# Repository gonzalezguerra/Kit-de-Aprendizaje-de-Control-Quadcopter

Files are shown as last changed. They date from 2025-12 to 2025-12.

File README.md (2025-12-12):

# Proyecto Educativo de Control con ESP32 y UAV (DXF + Firmware + Materiales)

Este repositorio reúne todos los recursos necesarios para que cualquier estudiante pueda **aprender control automático de manera económica y práctica**, utilizando una **ESP32**, sensores estándar y una estructura de dron diseñada para corte láser.

El proyecto incluye:
- Diseño del frame en **DXF**
- Firmware completo para **PlatformIO**
- Lista detallada de componentes y costos
- Guías prácticas para montaje y pruebas
- Material para extender el proyecto en cursos de control

---

# 🧩 Descripción General

Este proyecto está diseñado como una plataforma accesible para experimentar con:

- Control PID  
- Limitaciones físicas del control (saturación, ruido, retardo)
- Integración de sensores (IMU, magnetómetro, ToF)
- Actuadores (motores brushless + ESC)
- Modelación y simulación
- Construcción de UAV educativo

---

# 🛠️ Componentes y Costos Estimados

La siguiente tabla representa los costos aproximados para replicar la plataforma (valores en CLP).

> Esta tabla proviene del diseño original en LaTeX del proyecto, convertida a formato Markdown para uso en GitHub.

### **Tabla de costos (Markdown)**

| **Componente** | **Costo Estimado (CLP)** | **Proveedor** |
|---|---|---|
| **Cuerpo UAV** | | |
| Base madera 3 mm | $2.500 | Sodimac |
| Corte láser | $7.000 | Tago |
| Soportes PLA (impresión 3D) | ≈ $2.000 | Bibliotecas UC |
| **Alimentación y Actuadores** | | |
| Batería LiPo 11.1 V, 3000 mAh | $17.600 | Aliexpress |
| Motores brushless 2212 2200 KV (x4) | $36.000 | AFEL |
| Drivers ESC 30 A (x4) | $17.200 | Aliexpress |
| Conectores XT60 PCB | $7.500 | Aliexpress |
| Adaptadores XT60 a T | $8.000 | AFEL |
| Hélices fibra de carbono | $11.000 | AFEL |
| **Electrónica** | | |
| ESP32 (38 pines) | $5.000 | Aliexpress |
| MPU6050 (IMU) | $4.000 | AFEL |
| Magnetómetro HMC5883L | $3.500 | AFEL |
| Sensor distancia láser VL53L0X | $6.000 | AFEL |
| **TOTAL ESTIMADO** | **$127.300** | |

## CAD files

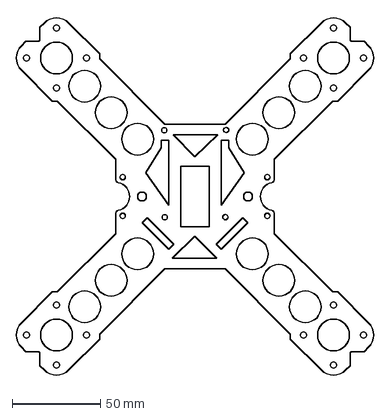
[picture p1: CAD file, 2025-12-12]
CorteDron.dxf
202.4 x 204.4 mm

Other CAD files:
Patas Quadcopter.f3d

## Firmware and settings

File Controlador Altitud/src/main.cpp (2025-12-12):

#include <Arduino.h>
#include <Wire.h>
#include <WiFi.h>
#include <LittleFS.h>
#include <FS.h>
#include <AsyncTCP.h>
#include <ESPAsyncWebServer.h>
#include <WiFiUdp.h>
#include <math.h> 

// Módulos
#include "sensores.h"
#include "MadgwickAHRS.h"
#include "LQRController.h"
#include "AltitudePID.h"
#include "Ultrasonic.h"

// ==========================================================
//                         CONSTANTES GLOBALES
// ==========================================================

// --- Frecuencias de Lazo ---
const int ATTITUDE_LOOP_HZ = 150;
const TickType_t xFrequencyAttitude = pdMS_TO_TICKS(1000 / ATTITUDE_LOOP_HZ);

const int ALTITUDE_LOOP_HZ = 40;
const TickType_t xFrequencyAltitude = pdMS_TO_TICKS(1000 / ALTITUDE_LOOP_HZ);

const int TELEMETRY_LOOP_HZ = 10; // Frecuencia de la telemetria. 5-20 Hz
const uint32_t TELEMETRY_INTERVAL_MS = 1000 / TELEMETRY_LOOP_HZ;

// Heartbeat variables (ahora solo como marcador, no como failsafe activo)
volatile uint32_t g_last_heartbeat_ms = 0;
const uint32_t HEARTBEAT_TIMEOUT_MS = 200; // Mantenido, pero no usado para failsafe

// --- Controladores y Filtros ---
MadgwickAHRS* ahrs;
LQRController* attitudeController;
AltitudePID* altController;

// --- Pines y Hardware ---
const int SDA_PIN = 21;
const int SCL_PIN = 22;
const int TRIG_PIN = 25;
const int ECHO_PIN = 26;

static const uint8_t PWM_PINS[4] = {32, 27, 4, 2}; // M1, M2, M3, M4
static const uint8_t LEDC_CH[4] = {0, 1, 2, 3}; // Canales LEDC para PWM
static const uint8_t LEDC_RES_BITS = 16;
static const uint32_t SERVO_FREQ_HZ = 50;      // Frecuencia PWM para ESCs
static const uint16_t PULSE_MIN_US = 1100;
static const uint16_t PULSE_MAX_US = 2100;

// Objetos de Sensores (Globales)
Adafruit_MPU6050 mpu;
Adafruit_HMC5883_Unified mag = Adafruit_HMC5883_Unified(12345);
Ultrasonic ultrasonic(TRIG_PIN, ECHO_PIN);
Adafruit_VL53L0X lox = Adafruit_VL53L0X();

// --- Calibración ---
float g_b[3] = {-0.01f, -0.06f, -0.02f};
float a_A[3][3] = {
    {1.002644, -0.004764, -0.004747 },
    { 0.050504, 0.985736, 0.003380 },
    { -0.004747, -0.002533, 0.979294 }
};
float a_b[3] = {0.268676, 0.140280, 0.152916};
float m_A[3][3] = {
    {1.114758, 0.013255, 0.007983},
    {0.013255, 1.048723, -0.005001},
    {0.007983, -0.005001, 1.027957}
};
float m_b[3] = {8.096708, -6.303482, -7.222026};

// GANANCIAS LQR
Matrix3x3 K_i_gains = {{{0.1f, 0.0f, 0.0f}, 
                        {0.0f, 0.1f, 0.0f}, 
                        {0.0f, 0.0f, 0.00f}}};
Matrix3x3 K_q_gains = {{{3.5f, 0.0f, 0.0f}, 
                        {0.0f, 3.5f, 0.0f}, 
                        {0.0f, 0.0f, 0.0f}}};
Matrix3x3 K_w_gains = {{{0.3f, 0.0f, 0.0f}, 
                        {0.0f, 0.3f, 0.0f}, 
                        {0.0f, 0.0f, 0.0f}}};

// ==========================================================
//               ESTADO COMPARTIDO (CON MUTEX)
// ==========================================================

SemaphoreHandle_t xStateMutex;

struct SharedControlState {
    float roll_deg, pitch_deg, yaw_deg; 
    Vector3f torques = {0.0f, 0.0f, 0.0f}; 
    float altitude_cm = 0.0f;
    float throttle_base = 0.0f;
} sharedState;

// Flags de Estado y Comandos (accedidas por red y tareas)
#define FLAG_ARMED (1 << 0) 
volatile int16_t g_setpoint_cm = 40; 
volatile uint8_t g_flags = 0; 
const float THROTTLE_HOVER = 0.45f;

// ==========================================================
//               FUNCIONES AUXILIARES (PWM, MATH)
// ==========================================================

static inline float clampf(float v, float lo, float hi) {
    if (v < lo) return lo;
    if (v > hi) return hi;
    return v;
}

static inline int8_t clamp_i8_deg(float d){
    if (d > 127) return 127;
    if (d < -128) return -128;
    return (int8_t)lrintf(d);
}

inline uint32_t periodUs() { return 1000000UL / SERVO_FREQ_HZ; }
inline uint32_t maxDuty() { return (1UL << LEDC_RES_BITS) - 1; }

uint32_t pulseToDuty(uint32_t pulse_us) {
    return (uint64_t)pulse_us * maxDuty() / periodUs();
}

void writePulseUs(uint8_t motor_index, uint16_t us) {
    if (us < PULSE_MIN_US) us = PULSE_MIN_US;
    if (us > PULSE_MAX_US) us = PULSE_MAX_US;
    ledcWrite(LEDC_CH[motor_index], pulseToDuty(us));
}

uint16_t floatToPulseUs(float value) {
        return PULSE_MIN_US + (uint16_t)(value * (PULSE_MAX_US - PULSE_MIN_US));
}

// ==========================================================
//    TAREA 1: CONTROL DE ACTITUD (CORE 1 - ALTA PRIORIDAD)
// ==========================================================
void Task_AttitudeControl(void *pvParameters) {
    Serial.println("Tarea de Actitud iniciada en Core 1.");
    TickType_t xLastWakeTime = xTaskGetTickCount();
    const float dt = 1.0f / ATTITUDE_LOOP_HZ;

    if ((g_flags & FLAG_ARMED) && (millis() - g_last_heartbeat_ms > HEARTBEAT_TIMEOUT_MS)) {
        Serial.println("[FAILSAFE] Heartbeat perdido. DESARMANDO MOTORES.");
        g_flags &= ~FLAG_ARMED;
    }       
    
    for (;;) {
        // ALTITUD
        Vector3f torques_local = {0.0f, 0.0f, 0.0f};

        float throttle_base_local;

        if (xSemaphoreTake(xStateMutex, (TickType_t)0) == pdTRUE) {
                throttle_base_local = sharedState.throttle_base;
                xSemaphoreGive(xStateMutex);
        }

        float roll_cmd = torques_local.x;
        float pitch_cmd = torques_local.y;
        float yaw_cmd = torques_local.z;


        float motor1_out = throttle_base_local -roll_cmd + pitch_cmd;
        float motor2_out = throttle_base_local -roll_cmd - pitch_cmd;
        float motor3_out = throttle_base_local + roll_cmd + pitch_cmd;
        float motor4_out = throttle_base_local + roll_cmd - pitch_cmd;

        if (g_flags & FLAG_ARMED) {
            writePulseUs(0, floatToPulseUs(clampf(motor1_out, 0.0f, 0.65f)));
            writePulseUs(1, floatToPulseUs(clampf(motor2_out, 0.0f, 0.65f)));
            writePulseUs(2, floatToPulseUs(clampf(motor3_out, 0.0f, 0.65f)));
            writePulseUs(3, floatToPulseUs(clampf(motor4_out, 0.0f, 0.65f)));
        } else {
    // Desarmado: Pulso Mínimo (1000us)
        for (int i = 0; i < 4; i++) writePulseUs(i, PULSE_MIN_US);
        }
    vTaskDelayUntil(&xLastWakeTime, xFrequencyAttitude);
    }
}

// ==========================================================
//    TAREA 2: CONTROL DE ALTITUD (CORE 1 - BAJA PRIORIDAD)
// ==========================================================
void Task_AltitudeControl(void *pvParameters) {
    Serial.println("Tarea de Altitud iniciada en Core 1.");
    TickType_t xLastWakeTime = xTaskGetTickCount();
    const float dt = 1.0f / ALTITUDE_LOOP_HZ;
    auto median3 = [](float a, float b, float c){ 
        if (a > b) { float t=a; a=b; b=t; } if (b > c) { float t=b; b=c; c=t; } if (a > b) { float t=a; a=b; b=t; } return b; 
    };

    for (;;) {
        VL53L0X_RangingMeasurementData_t m;
        lox.rangingTest(&m, false); float t1 = m.RangeMilliMeter;
        lox.rangingTest(&m, false); float t2 = m.RangeMilliMeter;
        lox.rangingTest(&m, false); float t3 = m.RangeMilliMeter;
        float tof_cm = 0.1f * median3(t1, t2, t3);
        // Fusión y Limitación
        float altitud_local = clampf(tof_cm, 0.0f, 150.0f); // 1.5 metros max

        // 2. Ejecutar Controlador PID
        float altitud_deseada = (float)g_setpoint_cm;
        float pid_correction = 0.0f;
        float throttle_base_local = THROTTLE_HOVER;

        if (g_flags & FLAG_ARMED) {
            pid_correction = altController->update(altitud_deseada, altitud_local, dt);
            throttle_base_local = THROTTLE_HOVER + pid_correction;
            throttle_base_local = clampf(throttle_base_local, 0.0f, 0.65f);
            Serial.printf("Setpoint: %d cm, medida: %.1f cm, throttle_base: %.2f, (P: %.3f, I: %.3f, D: %.3f)\n",
                        g_setpoint_cm, altitud_local, throttle_base_local,
                        altController->lastP(),
                        altController->lastI(),
                        altController->lastD());
        }
        // 3. Actualizar el Estado Compartido (¡CON MUTEX!)
        if (xSemaphoreTake(xStateMutex, (TickType_t)5) == pdTRUE) {
            sharedState.altitude_cm = altitud_local;
            sharedState.throttle_base = throttle_base_local;
            xSemaphoreGive(xStateMutex);
        }
        vTaskDelayUntil(&xLastWakeTime, xFrequencyAltitude);
    }
}

// ==========================================================
//                   LÓGICA DE TELEMETRÍA (IOT)
//                     (CORE 0 - ASÍNCRONO)
// ==========================================================

// --- Variables de Red ---
AsyncWebServer server(80);
AsyncWebSocket ws("/ws");
WiFiUDP udpRx;
WiFiUDP udpTx;
static const uint16_t UDP_PORT_TX = 4000;
static const uint16_t UDP_PORT_RX = 4001;
static const IPAddress BROADCAST_IP(192,168,4,255);
static uint8_t g_seq = 0;
static IPAddress lastClientIP = IPAddress(0,0,0,0);

struct __attribute__((packed)) Telemetry {
        int16_t yaw_cdeg; 
        int8_t   pitch_d;
        int8_t   roll_d; 
        uint16_t alt_cm;
        uint8_t  flags; 
        uint8_t  seq;
};

static constexpr size_t TELEMETRY_SIZE = sizeof(Telemetry);
static uint8_t telemetryBuf[TELEMETRY_SIZE];
static Telemetry* telPtr = reinterpret_cast<Telemetry*>(telemetryBuf);

// --- Funciones de IOT ---

static void handleUdpRx() {
    int pkt = udpRx.parsePacket();
    if (pkt <= 0) return;
    uint8_t buf[64]; int r = udpRx.read(buf, sizeof(buf));
    if (r <= 0) return;
    g_last_heartbeat_ms = millis(); 
    if (r == 2) {
    int16_t sp = (int16_t)((uint16_t)buf[0] | ((uint16_t)buf[1]<<8));
    g_setpoint_cm = constrain(sp, 0, 300);
    }
}

static void fillTelemetryFromSensors() {
    float r=0.0f, p=0.0f, y=0.0f, alt=0.0f;
    // Leer el estado compartido de forma segura
    if (xSemaphoreTake(xStateMutex, (TickType_t)5) == pdTRUE) {
        r = sharedState.roll_deg;
        p = sharedState.pitch_deg;
        y = sharedState.yaw_deg;
        alt = sharedState.altitude_cm;
        xSemaphoreGive(xStateMutex);
    }   
    // Llenar el paquete de telemetría con datos escalados
    telPtr->yaw_cdeg = (int16_t)lrintf(clampf(y, -180.0f, 180.0f) * 100.0f);
    telPtr->pitch_d  = clamp_i8_deg(p);
    telPtr->roll_d   = clamp_i8_deg(r);
    telPtr->alt_cm   = (uint16_t)lrintf(clampf(alt, 0.0f, 65535.0f));
    telPtr->flags    = g_flags;
    telPtr->seq      = g_seq++;
}

static void sendTelemetry(const uint8_t *buf, size_t len) {
    if (ws.count() > 0) {
        ws.binaryAll((const char*)buf, len); 
        return; 
    }

    if (lastClientIP[0] != 0) { 
        udpTx.beginPacket(lastClientIP, UDP_PORT_TX); udpTx.write(buf, len); udpTx.endPacket(); return;
    }
    if (WiFi.softAPgetStationNum() > 0) {
        udpTx.beginPacket(BROADCAST_IP, UDP_PORT_TX); udpTx.write(buf, len); udpTx.endPacket();
    }
}

static void onWsEvent(AsyncWebSocket *serverPtr, AsyncWebSocketClient *client, AwsEventType type, void *arg, uint8_t *data, size_t len) {
    switch(type){
        case WS_EVT_CONNECT:
            lastClientIP = client->remoteIP();
            Serial.printf("[WS] Cliente conectado: %s\n", lastClientIP.toString().c_str());
            client->client()->setNoDelay(true);
            break;

        case WS_EVT_DISCONNECT:
            if (g_flags & FLAG_ARMED) { 
                Serial.println("[FAILSAFE] Cliente desconectado. DESARMANDO.");
                g_flags &= ~FLAG_ARMED; 
            } else {
                Serial.println("[WS] Cliente desconectado.");
            }
            if (lastClientIP == client->remoteIP()) lastClientIP = IPAddress(0,0,0,0);
            break;

        case WS_EVT_DATA: { // <--- AQUI AGREGUE LA LLAVE DE APERTURA
            AwsFrameInfo *info = (AwsFrameInfo*)arg;
            
            // Solo procesamos si es un mensaje de texto completo y es el frame final
            if (info->final && info->index == 0 && info->len == len && info->opcode == WS_TEXT) {
                
                // Asegurar terminación nula
                data[len] = 0;
                String mensaje = (char*)data;
                
                int nuevo_setpoint = -1;
                
                // Lógica de parseo
                if (mensaje.startsWith("ALT:")) {
                    nuevo_setpoint = mensaje.substring(4).toInt();
                } else if (isdigit(mensaje.charAt(0))) {
                    nuevo_setpoint = mensaje.toInt();
                }

                if (nuevo_setpoint >= 0) {
                    g_setpoint_cm = constrain(nuevo_setpoint, 0, 300);
                    g_last_heartbeat_ms = millis(); 
                    Serial.printf("[WS] Setpoint recibido: %d cm\n", g_setpoint_cm);
                } else {
                    Serial.printf("[WS] Comando no reconocido: %s\n", mensaje.c_str());
                }
            }
            break; 
        }

        default: break;
    }
}

static void setupAP(){
    WiFi.mode(WIFI_AP);
    WiFi.softAP("DRON_ESP32","12345678");
    WiFi.softAPConfig(IPAddress(192,168,4,1), IPAddress(192,168,4,1), IPAddress(255,255,255,0));
}

static void setupFS(){ if (!LittleFS.begin()) { LittleFS.format(); LittleFS.begin(); } }

static void setupServer(){
    ws.onEvent(onWsEvent);
    server.addHandler(&ws);

    server.on("/arm", HTTP_GET, [](AsyncWebServerRequest *request){
        g_last_heartbeat_ms = millis();
        g_flags |= FLAG_ARMED;
        Serial.println("[HTTP] ARMADO. Motores listos.");
        request->send(200, "text/plain", "ARMED");
    });

    server.on("/disarm", HTTP_GET, [](AsyncWebServerRequest *request){
        g_flags &= ~FLAG_ARMED;
        Serial.println("[HTTP] DESARMADO. Motores detenidos.");
        request->send(200, "text/plain", "DISARMED");
    });

    server.on("/set_alt", HTTP_GET, [](AsyncWebServerRequest *request){
        if (request->hasParam("cm")) {
            int cm = request->getParam("cm")->value().toInt();
            g_setpoint_cm = (int16_t)constrain(cm, 0, 300);
            g_last_heartbeat_ms = millis();
            Serial.printf("[HTTP] Setpoint actualizado: %d cm\n", g_setpoint_cm);
            request->send(200, "text/plain", "OK");
        } else {
            // Agrega este log para depurar si el cliente manda mal el parametro
            Serial.println("[HTTP ERROR] Petición a /set_alt sin parámetro 'cm'");
            
            // Listar qué parametros llegaron para ver cómo lo está enviando el dashboard
            int params = request->params();
            for(int i=0;i<params;i++){
                AsyncWebParameter* p = request->getParam(i);
                Serial.printf("Param recibido: %s = %s\n", p->name().c_str(), p->value().c_str());
            }
            request->send(400, "text/plain", "Missing cm parameter");
        }
    });

    server.serveStatic("/", LittleFS, "/").setDefaultFile("index.html").setCacheControl("no-cache");
    server.begin();
}

// ==========================================================
//                   CONFIGURACIÓN PRINCIPAL
// ==========================================================
void setup() {
    Serial.begin(115200);
    delay(100);
   Serial.println("Iniciando sistema DUAL-CORE...");

    // 1. Inicializar Sensores y Controladores
   Wire.begin(SDA_PIN, SCL_PIN, 400000); 
   if(!mpu.begin()) { 
        Serial.println("MPU6050 no responde."); 
        while(1) 
        delay(10); 
    }
    mpu.setAccelerometerRange(MPU6050_RANGE_2_G);
    mpu.setGyroRange(MPU6050_RANGE_500_DEG);
    mpu.setFilterBandwidth(MPU6050_BAND_21_HZ);
    if(!mag.begin()) { 
        Serial.println("HMC5883L no responde."); 
        while(1) 
        delay(10); 
    }
    if(!lox.begin()) { 
        Serial.println("VL53L0X (ToF) no responde."); 
        while (1) 
        delay(10); 
    }
    lox.startRangeContinuous(); 
    Serial.println("Sensores inicializados.");

    // Inicializar Controladores
    // il PID
    ahrs = new MadgwickAHRS(0.1f);
    attitudeController = new LQRController();
    attitudeController->setGains(K_i_gains, K_q_gains, K_w_gains);
    altController = new AltitudePID();

    // Dale tu taglio Goatcaz
    float alt_kp = 0.0065f; 
    float alt_ki = 0.017f;
    float alt_kd = 0.002f;

    altController->setGains(alt_kp, alt_ki, alt_kd);         // PID
    altController->setLimits(-0.0f, 0.2f);
    altController->setAntiWindup(-5.0f, 5.0f);

    // 2. Setup de PWM (Motores)
    Serial.println("Configurando PWM y Armado de ESCs...");
    for (int i = 0; i < 4; i++) {
        ledcSetup(LEDC_CH[i], SERVO_FREQ_HZ, LEDC_RES_BITS);
        ledcAttachPin(PWM_PINS[i], LEDC_CH[i]);
        writePulseUs(i, PULSE_MIN_US);
    }
    delay(3000); 
    Serial.println("ESCs armados. Motores en IDLE (1000us).");

    // 3. Crear Mutex y Comunicación IoT (CORE 0)

    xStateMutex = xSemaphoreCreateMutex();
    if (xStateMutex == NULL) { 
        Serial.println("Error al crear Mutex!");
        while(1); 
    } else {
    setupAP();
    WiFi.setSleep(false);
    setupFS();
    setupServer();
    udpTx.begin(WiFi.softAPIP(), 0);
    size_t udp_status = udpRx.begin(UDP_PORT_RX); 
    if (udp_status != 1) { 
        Serial.println("[ERROR FATAL] Fallo al iniciar UDP RX en puerto 4001.");
        while(1); 
    }
    }
    
    // 4. Crear Tareas de FreeRTOS (Core 1 para Control)
    xTaskCreatePinnedToCore(Task_AttitudeControl, "Attitude", 10000, NULL, 2, NULL, 1); 
    xTaskCreatePinnedToCore(Task_AltitudeControl, "Altitude", 4096, NULL, 2, NULL, 1);

    Serial.println("Control de vuelo en Core 1. Comunicaciones en Core 0.");
    Serial.println(">>> Accede a http://192.168.4.1 y usa /arm para activar el vuelo. <<<");
}


// ==========================================================
//             TAREA 3: BUCLE PRINCIPAL (CORE 0)
// ==========================================================
// --- TAREA 3: BUCLE PRINCIPAL (CORE 0) ---
void loop() {
    static uint32_t lastTelemetryTx = 0;
    uint32_t now = millis();
    static uint32_t lastCleanup = 0;
    const uint32_t CLEANUP_INTERVAL_MS = 1000;

    // 1. Recibir Comandos UDP
    handleUdpRx();

    // 2. Mantenimiento de Conexiones (Aislado al inicio del loop)
    // HACEMOS LA LIMPIEZA AHORA, ANTES DE ENVIAR LA TELEMETRÍA.
    if (now - lastCleanup >= CLEANUP_INTERVAL_MS) {
        lastCleanup = now;
        ws.cleanupClients(); 
    }
    
    // 3. Enviar Telemetría (10 Hz)
    bool is_client_present = (ws.count() > 0 || WiFi.softAPgetStationNum() > 0);
    if (is_client_present && (now - lastTelemetryTx >= TELEMETRY_INTERVAL_MS)) {
        lastTelemetryTx = now;
        fillTelemetryFromSensors();
        sendTelemetry(telemetryBuf, TELEMETRY_SIZE);
    }
    
    // Cede el tiempo de CPU, dando más espacio al scheduler
    vTaskDelay(pdMS_TO_TICKS(5)); 
}

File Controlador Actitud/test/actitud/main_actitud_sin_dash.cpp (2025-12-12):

#include <Arduino.h>
#include <Wire.h>
#include "sensores.h"
#include "MadgwickAHRS.h"   // Filtro Madgwick
#include "LQRController.h"  // Controlador LQR
#include "AltitudePID.h"    // Controlador de Altura PID
#include "Ultrasonic.h"     // Sensor Ultrasónico

// clampf: Función auxiliar para limitar valores flotantes
static inline float clampf(float v, float lo, float hi) {
    if (v < lo) return lo;
    if (v > hi) return hi;
    return v;
}

// --- Frecuencias de Lazo ---
// Frecuencia del lazo de actitud (150 Hz = 6.67ms). Rango entre 150 y 250 Hz
const int ATTITUDE_LOOP_HZ = 150;
const TickType_t xFrequencyAttitude = pdMS_TO_TICKS(1000 / ATTITUDE_LOOP_HZ);

// Frecuencia del lazo de altitud (40 Hz = 25ms)
const int ALTITUDE_LOOP_HZ = 40;
const TickType_t xFrequencyAltitude = pdMS_TO_TICKS(1000 / ALTITUDE_LOOP_HZ);

// --- Controladores y Filtros ---
MadgwickAHRS* ahrs;
LQRController* attitudeController;
AltitudePID* altController;

// --- Pines para sensores ---
const int SDA_PIN = 21;
const int SCL_PIN = 22;
const int TRIG_PIN = 25;
const int ECHO_PIN = 26;

// ----------------------------- PWM ------------------------------

// Pines de motores (PWM)
static const uint8_t PWM_PINS[4] = {32, 27, 4, 2}; // M1, M2, M3, M4
static const uint8_t LEDC_CH[4] = {0, 1, 2, 3}; // Canales LEDC para PWM

// Parametros de PWM
static const uint8_t LEDC_RES_BITS = 16; // Resolución de 16 bits
static const uint32_t SERVO_FREQ_HZ = 50; // Frecuencia típica de ESCs (50 Hz)
static const uint16_t PULSE_MIN_US = 1100; // Minimo para que giren
static const uint16_t PULSE_MAX_US = 2100; // Maximo para que giren
static const uint16_t PULSE_IDLE_US = 1050; // IDLE

// AUX PWM
inline  uint32_t periodUs() {
    return 1000000UL / SERVO_FREQ_HZ;       // 20000us para 50Hz
}
inline uint32_t maxDuty() {
    return (1UL << LEDC_RES_BITS) - 1;      // 65535 para 16 bits
}

/**
 * @brief Convierte microsegundos de pulso a valor de duty cycle para PWM.
 */
uint32_t pulseToDuty(uint32_t pulse_us) {
    return (uint64_t)pulse_us * maxDuty() / periodUs();
}

/**
 * @brief Escribe un ancho de pulso en microsegundos a un canal de motor
 */
void writePulseUs(uint8_t motor_index, uint16_t us) {
    if (us < PULSE_MIN_US) us = PULSE_MIN_US;
    if (us > PULSE_MAX_US) us = PULSE_MAX_US;
    ledcWrite(LEDC_CH[motor_index], pulseToDuty(us));
}

/**
 * @brief Convierte la salida del mezclador a un pulso
 */
uint16_t floatToPulseUs(float value) {
    return PULSE_MIN_US + (uint16_t)(value * (PULSE_MAX_US - PULSE_MIN_US));
}

// ----------------------------- fin PWM ------------------------------

// Objetos de Sensores (Globales)
Adafruit_MPU6050 mpu;
Adafruit_HMC5883_Unified mag = Adafruit_HMC5883_Unified(12345);
Ultrasonic ultrasonic(TRIG_PIN, ECHO_PIN);
Adafruit_VL53L0X lox = Adafruit_VL53L0X();

// Kill switch (Interruptor de emergencia)
volatile bool g_ESTOP_ACTIVADO = false;

// Matrices de Calibración (Globales)
//float g_b[3] = { -0.01f + 0.00056284f, -0.06f + 0.00180133f, -0.02f + 0.00563336f };
float g_b[3] = {-0.01f, -0.06f, -0.02f};
float a_A[3][3] = {
    {1.002644, -0.004764, -0.004747 },
    { 0.050504, 0.985736, 0.003380 },
    { -0.004747, -0.002533, 0.979294 }
};

float a_b[3] = {0.268676, 0.140280, 0.152916};
float m_A[3][3] = {
    {1.114758, 0.013255, 0.007983},
    {0.013255, 1.048723, -0.005001},
    {0.007983, -0.005001, 1.027957}
};
float m_b[3] = {8.096708, -6.303482, -7.222026};

float a_calibrado[3];
float g_calibrado[3];
float m_calibrado[3];
float roll, pitch, yaw;

// GANANCIAS LQR (Globales)

Matrix3x3 K_i_gains = {{{0.06f, 0.0f, 0.0f}, 
                        {0.0f, 0.06f, 0.0f}, 
                        {0.0f, 0.0f, 0.0f}}};
Matrix3x3 K_q_gains = {{{1.7f, 0.0f, 0.0f}, 
                        {0.0f, 1.7f, 0.0f}, 
                        {0.0f, 0.0f, 0.0f}}};
Matrix3x3 K_w_gains = {{{0.25f, 0.0f, 0.0f}, 
                        {0.0f, 0.25f, 0.0f}, 
                        {0.0f, 0.0f, 0.0f}}};

// Estado Compartido
// Estos son los datos que las tareas se comunican entre sí.
// Deben ser protegidos por un "Mutex" para evitar corrupción de datos.
SemaphoreHandle_t xStateMutex;
struct SharedControlState {
    Quaternion q_current = {1.0f, 0.0f, 0.0f, 0.0f}; // Escrito por Tarea_Actitud
    Vector3f w_current = {0.0f, 0.0f, 0.0f};         // Escrito por Tarea_Actitud
    float altitude_cm = 0.0f;                        // Escrito por Tarea_Altitud
    float throttle_base = 0.0f;                      // Escrito por Tarea_Altitud
    Vector3f torques = {0.0f, 0.0f, 0.0f};           // Escrito por Tarea_Actitud
} sharedState;

// ==========================================================
//    TAREA 1: LAZO DE ACTITUD Y ESTABILIZACIÓN (200 Hz)
// ==========================================================
void Task_AttitudeControl(void *pvParameters) {
    Serial.println("Tarea de Actitud iniciada en Core 1.");
    TickType_t xLastWakeTime;
    const float dt = 1.0f / ATTITUDE_LOOP_HZ; // dt es constante

    // Variables de estado
    sensors_event_t mag_raw; // Para el magnetómetro
    sensors_event_t a, g, t; // Eventos del MPU6050
    sensors_event_t m;       // Evento del HMC5883

    // Arrays para datos crudos (en m/s^2 y rad/s)
    float a_raw[3], g_raw[3], m_raw[3];
    
    // Variables finales para los filtros (en m/s^2 y rad/s)
    float ax, ay, az, gx, gy, gz, mx, my, mz;

    xLastWakeTime = xTaskGetTickCount();

    for (;;) {
        // 1. Lectura de Sensores IMU
        mpu.getEvent(&a, &g, &t); // Lee Accel y Gyro
        mag.getEvent(&m);         // Lee Magnetómetro

        // Cargar datos crudos en arrays
        a_raw[0] = a.acceleration.x;
        a_raw[1] = a.acceleration.y;
        a_raw[2] = a.acceleration.z;
        
        g_raw[0] = g.gyro.x;
        g_raw[1] = g.gyro.y;
        g_raw[2] = g.gyro.z;

        m_raw[0] = m.magnetic.x;
        m_raw[1] = m.magnetic.y;
        m_raw[2] = m.magnetic.z;

        // --- 2. Aplicar Calibraciones (de sensores.cpp) ---
        ax = a_A[0][0] * (a_raw[0] - a_b[0]) + a_A[0][1] * (a_raw[1] - a_b[1]) + a_A[0][2] * (a_raw[2] - a_b[2]);
        ay = a_A[1][0] * (a_raw[0] - a_b[0]) + a_A[1][1] * (a_raw[1] - a_b[1]) + a_A[1][2] * (a_raw[2] - a_b[2]);
        az = a_A[2][0] * (a_raw[0] - a_b[0]) + a_A[2][1] * (a_raw[1] - a_b[1]) + a_A[2][2] * (a_raw[2] - a_b[2]);

        // Calibrar Giroscopio: (g_raw - b)
        gx = g_raw[0] - g_b[0];
        gy = g_raw[1] - g_b[1];
        gz = g_raw[2] - g_b[2];

        // Imprimir los valores calibrados GYRO
        //Serial.print("GYRO_CALIBRADO [gx, gy, gz]: ");
        //Serial.print(gx, 6); // Imprimir con 6 decimales
        //Serial.print(", ");
        //Serial.print(gy, 6);
        //Serial.print(", ");
        //Serial.println(gz, 6);
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

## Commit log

2025-12-12 Add CorteDron.dxf file
    [CorteDron.dxf]
2025-12-12 Update BancoActitud documentation
    Removed comparison of motors and additional documentation offer.
